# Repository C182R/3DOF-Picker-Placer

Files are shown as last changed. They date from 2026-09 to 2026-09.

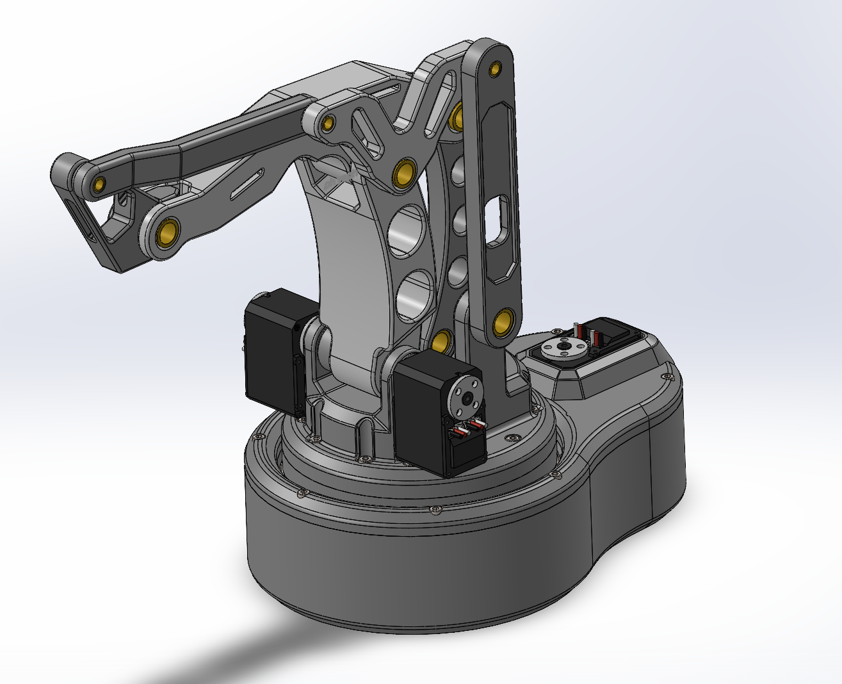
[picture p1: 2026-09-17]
docs/images/assembly with servos v3.png

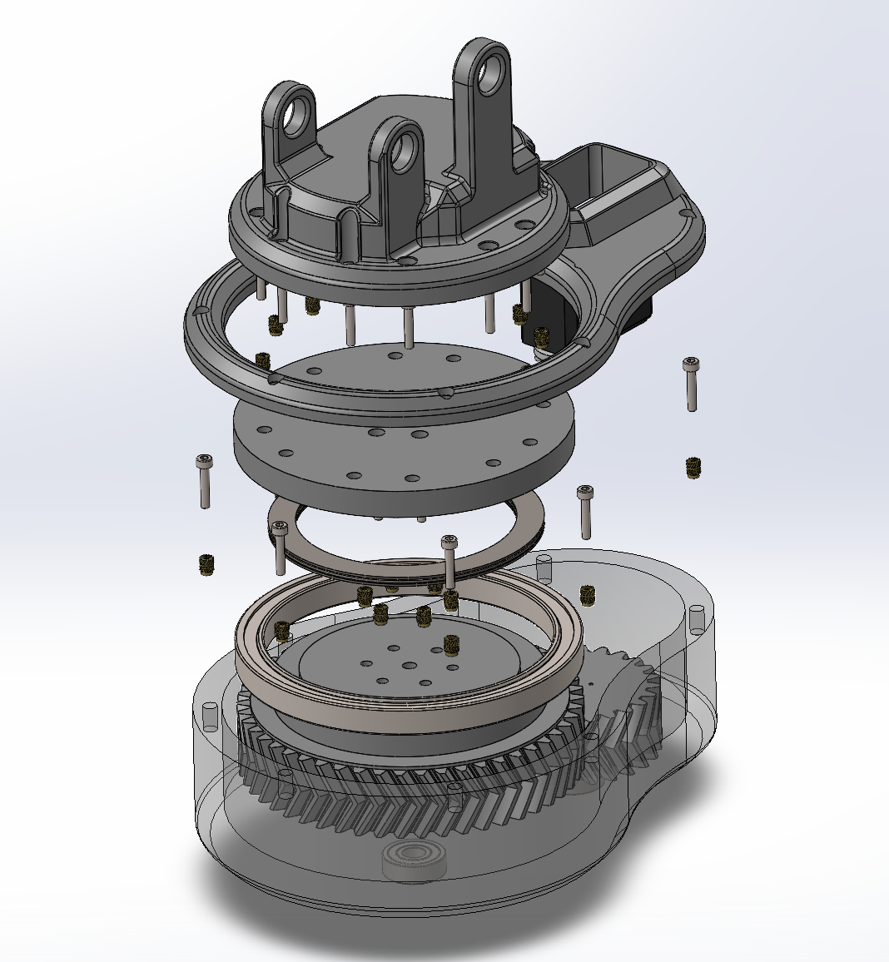
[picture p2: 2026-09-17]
docs/images/base assembly exploded view v3.png

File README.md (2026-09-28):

# 3DOF-Picker-Placer: Palletino

*Work-in-progress*



A cheap, easily-assembled, trainable 3-DOF robot arm, designed so anyone could build one from a parts list. Built around a parallelogram linkage topology referenced from Fanuc/KUKA/Panasonic palletizing robots, with topology-optimized structural links for FDM printing.

## Goals
- Cheap, off-the-shelf smart servos + printed structure, no exotic parts
- Easy to assemble: clear BOM, standard fasteners, no proprietary hardware
- Precise, not sprawling; deliberately 3 DOF (waist / shoulder / elbow) instead of chasing 6 DOF. The bet is that a tight, repeatable 3-DOF arm is more useful than a loose 6-DOF one, and it keeps cost and build complexity down
- Trainable — kinesthetic teach-and-repeat via torque-disabled smart servos, no separate programming step needed to record a motion (in progress)
- Modular at the tool end: swappable tool heads (dial gauge for precision validation, vacuum head for palletizing/pick-and-place, optional 4th-DOF wrist) instead of building capability into the arm itself

## Status
V2 base (waist joint, herringbone 2:1 reduction, swivel bearing) designed and being added to the repo. Firmware not yet started. See devlogs for the full history.

### Specs at a glance
	
- DOF 3 (waist, shoulder, elbow) + optional 4th-DOF tool head
- Actuators	3× Feetech STS3215 smart servo, daisy-chained
- Controller	ESP32 + Waveshare Bus Servo Adapter (UART)
- Power	USB-C PD (20V, primary) or XT60 bench/battery tap (alternate) → 12V servo bus / 5V logic
- Structure	FDM PETG (V1/V2), aluminum machining planned for later versions
- Base reduction	2:1 herringbone gear, waist joint

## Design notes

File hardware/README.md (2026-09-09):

# /hardware

SolidWorks source files and exports are here. The most up-to-date design files of the project

```
hardware/
├── solidworks/        # .SLDPRT, .SLDASM, .SLDDRW source files
├── step/               # .STEP exports — for anyone opening this in non-SolidWorks CAD, ready to slice
```

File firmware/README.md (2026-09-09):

# /firmware

ESP32 control code goes here once it exists. Planned scope:

- STS3215 bus servo driver over UART (via the Waveshare Bus Servo Adapter)
- Joint position read/write + torque-disable for kinesthetic teach mode
- Teach-and-repeat: record demonstrated motions, play them back
- Eventually: a tool-head interface layer so swapping tool heads (dial gauge, vacuum, 4th-DOF wrist) doesn't require rewriting the core motion code

Nothing's written yet.. this is a placeholder so the repo structure is ready when it is.

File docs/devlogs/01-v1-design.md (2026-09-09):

# Robot Arm Build — Devlog #1: V1 Design

**Date:** August 25, 2026

## Overview

This is v1 of the overall robot arm build, which is a 3 DOF antagonistic drive pick and placer, inspired by factory palletizing robots. The first physical version of a linkage-driven arm I've been working on in SolidWorks. I've already got a few issues with this version, just from looking at it on screen, but I'm going to 3D print it to see how it actually behaves in the real world before making changes.

## Design Approach
I used existing automation robot references for primitive geometry; I pulled references from Fanuc, KUKA, and Panasonic industrial/palletizing robots. These companies have decades of field-proven arm geometry behind them, so rather than guessing at joint offsets and link ratios from scratch, I used their designs as a sanity check for what actually works in practice. I'm already researching their electronic work using different control options like CANBUS and EtherCAT to implement (at least one version) into this robot.

**Topology optimization for the big structural pieces**
For the largest (by volume) components (anything with organic-looking cutouts or holes) I ran SolidWorks' topology optimization instead of hand-sketching lightening patterns. To make sure my studies were actually improving my design instead of making it worse, I cross referenced different parts across the industry (excavators, cranes, and other heavy equipment, since an excavator is what inspired me to create this robot) and used my knowledge in steel mechanics to see if a part would hold from a glance.

**Industrial robot references for the geometry**
For the practical link geometry and proportions, I pulled references from Fanuc, KUKA, and Panasonic industrial/palletizing robots. These companies have decades of field-proven arm geometry behind them, so rather than guessing at joint offsets and link ratios from scratch, I used their designs as a sanity check for what actually works in practice.

**DFM for FDM — with an eye toward aluminum later**
I designed with FDM 3D printing's strengths and weaknesses specifically in mind: layer orientation, load direction relative to layer lines, wall thickness, rather than just printing "machined part" geometry and hoping it holds up. At the same time, I kept track of which components are candidates to eventually remake in aluminum if the design is proven out, so the plastic-specific DFM choices don't paint me into a corner for a metal version down the line.

## What's Next
Print V1 and put it through real motion / hand-stress testing to confirm (or rule out) the issues I'm already suspecting. Then, I'll revise the design based on what breaks, binds, or flexes more than it should have. After, I'll start on the electronics side, although I'm going in with limited parts on hand, so that'll be its own challenge.

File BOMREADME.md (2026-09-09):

BOM.csv is for review.
BOM.md is the mockup as a basis for the main components needed.
In the future after accurate cost calculation, the price of assembling one robot with only the necessary components will be compiled into another document

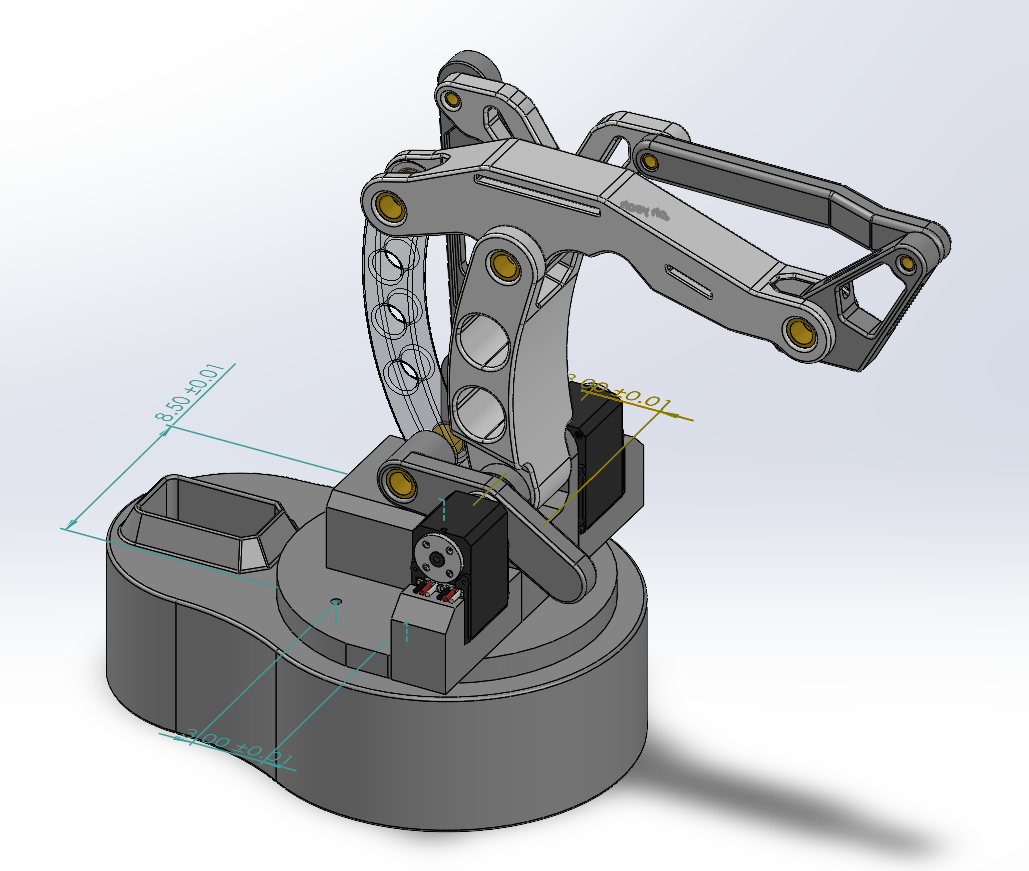
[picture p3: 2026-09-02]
docs/images/v2-base-overview.png

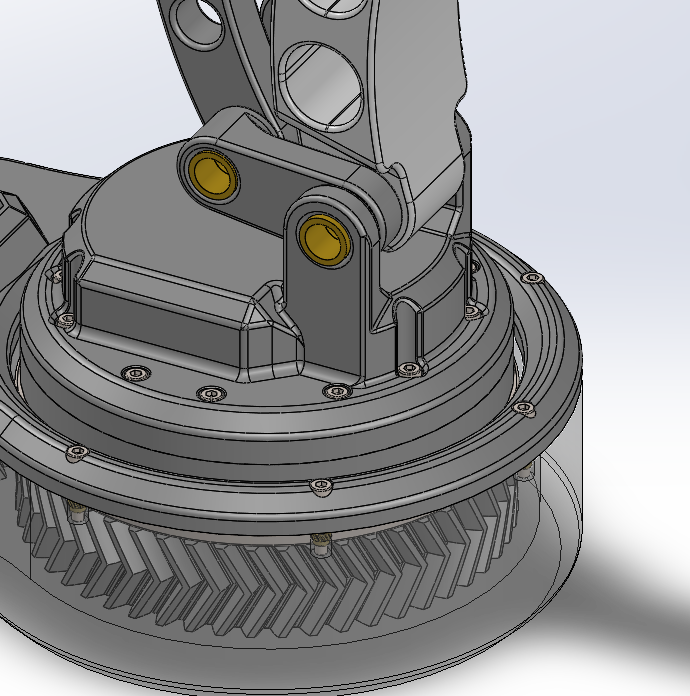
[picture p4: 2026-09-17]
docs/images/design change in v3.png

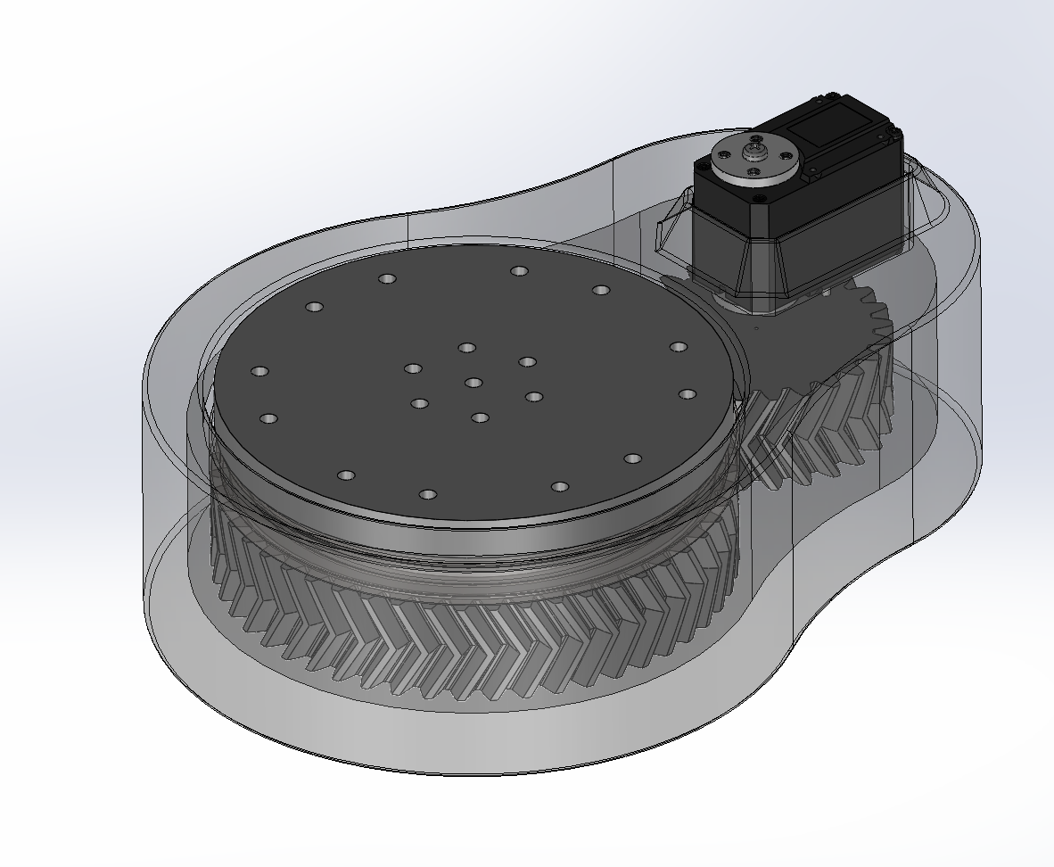
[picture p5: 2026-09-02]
docs/images/v2-base-cutaway.png

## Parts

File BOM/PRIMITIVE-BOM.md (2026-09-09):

# Bill of Materials (living doc)

Components finalized so far. Pricing/links intentionally left blank. 3D printed parts should have files included in /hardware

## Actuation
| Qty | Part | Notes |
|---|---|---|
| 3 | Feetech STS3215 smart servo (12V, 30 kg·cm, 1:345) | Waist, shoulder, elbow. Built-in 12-bit magnetic encoder + serial bus daisy-chain + torque-disable for kinesthetic teaching |

## Control
| Qty | Part | Notes |
|---|---|---|
| 1 | ESP32 dev board | Main controller |
| 1 | Waveshare Bus Servo Adapter (A) | Jumper set to UART mode; drives the STS3215 daisy chain |

## Power
| Qty | Part | Notes |
|---|---|---|
| 1 | CH224K USB-C PD trigger board | Set to 20V — mandatory PDO on 65W+ chargers |
| 1 | USB-C receptacle / breakout | Mount the CH224K's own USB-C connector directly at the panel edge rather than routing through a separate panel-mount breakout — many cheap breakouts drop the CC lines and silently kill PD negotiation |
| 1 | USB-C PD charger, 65W+ | USB-C laptop charger works fine, but should be separate from USB C data cable |
| 1 | XL4016 buck converter | Trimmed to 12V for servo bus |
| 1 | MP1584 mini buck converter | Set to 5V, feeds ESP32 VIN |
| 1 | 7.5A inline fuse | |
| 1 | SPST master switch | |
| 1 | 2200µF 25V low-ESR electrolytic cap | Across servo adapter power terminals |
| 1 | SMBJ14A TVS diode | Across servo adapter power terminals |
| 1 | XT60 connector | Tapped upstream of fuse, for bench supply |
| 1 | Mini voltmeter/ammeter module | Diagnostics |

## Structure
| Qty | Part | Notes |
|---|---|---|
| — | PETG filament | Primary structural material for FDM prints |
| — | M3 shoulder screws | Pivot pins — do not substitute printed pins |
| — | Herringbone ring gear + pinion (base) | 2:1 reduction, printed |
| — | Swivel bearing interface (base) | Simple flat swivel, not crossed-roller |
| 1 | Mini voltmeter/ammeter module | Diagnostics |

### Input Path B -- XT60 (bench supply, battery)
| Qty | Part | Notes |
|---|---|---|
| 1 | XT60 connector | Tapped upstream of fuse, for bench supply |
| - | External ~20V DC source | Bench supply, or a 5S LiPo + charger (~18.5–21V) if going battery-powered |

## Structure
| Qty | Part | Notes |
|---|---|---|
| — | PETG filament | Primary structural material for FDM prints. PLA will suffice for any low friction surface |
| — | M3 shoulder screws | (Ideally) Pivot pins. Substitute with PETG rods included in /hardware for primitive version |
| — | Herringbone ring gear + pinion (base) | 2:1 reduction, PETG printed |
| — | Swivel bearing interface (base) | Simple thrust roller bearing + roller/ ball bearing |

## Not yet finalized
- Vacuum pickup tool head (pump, nozzle, fittings)
- Dial gauge + mount
- Optional 4th-DOF wrist module

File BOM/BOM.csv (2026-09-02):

Category | Part Name | Spec / Size | Pack Qty | Cart Qty | Unit Price | Line Total | Notes | Link
Servos | FEETECH STS3215 30kg Smart Servo | 12V bus servo w/ magnetic encoder | 2 pcs/pack | 2 | $48.99 | $97.98 | 2x 2-packs = 4 servos total; 5% multi-buy discount noted in cart
Control | Waveshare Bus Servo Driver Board | Serial bus power + control circuit | 2 pcs/pack | 1 | $19.99 | $19.99 | ST/SC series bus servos. Jumper on position A for UART
Control | ELEGOO ESP-32 Dev Board | ESP-WROOM-32 USB-C WiFi/BT | 3 pcs/pack | 1 | $19.99 | $19.99 | Main controller board
Power | Seloky USB-C PD Trigger Board | PD/QC decoy, DIP-selectable 5-20V | 4 pcs/pack | 1 | $9.99 | $9.99 | CH224K-based. SET DIP TO 20V (not 12V). Mount at panel edge - use its own USB-C socket
Power | HiLetgo XL4016 Buck Converter | 4-40V to 1.25-36V 8A 200W | 2 pcs/pack | 1 | $10.99 | $10.99 | 20V->12V servo rail. Set output to 12.0V BEFORE connecting any load
Power | EBOOT MP1584EN Buck Converter | 24V to 12/9/5/3V adjustable | 6 pcs/pack | 1 | $12.55 | $12.55 | 12V->5V ESP32 rail. Taps rail UPSTREAM of E-stop so logic survives a stop
Power | Rubycon Electrolytic Capacitor | 2200uF 25V 12.5x25mm low-ESR | multi-pack | 1 | $6.99 | $6.99 | Across servo adapter power terminals. Stripe to ground
Protection | Chanzon SMBJ15A TVS Diodes | 600W 15V unidirectional | 50 pcs/pack | 1 | $5.99 | $5.99 | Across servo adapter power terminals. Banded end to +12V
Protection | Automotive Blade Fuse Assortment Kit | 5-30A ATC/ATO | 140 pcs/pack | 1 | $9.97 | $9.97 | Start with 7.5A, step to 10A only if nuisance blows
Protection | 10AWG Inline Fuse Holder | 40A ATC blade | 4 pcs/pack | 1 | $9.99 | $9.99 | 7.5A fuse on servo rail. Oversized for 16AWG - watch the crimp
Safety | TWTADE 22mm E-Stop Mushroom Button | 2NC 10A 600V | 1 pc | 1 | $14.99 | $14.99 | 1 contact breaks servo rail, 1 contact to ESP32 GPIO as sense
Switches | Nilight 90012E Rocker Toggle Switch | SPST 15A 250V / 20A 125V | 5 pcs/pack | 1 | $9.34 | $9.34 | Master power switch (storage/transport, not emergency)
Diagnostics | bayite DC Volt Meter | 0-30V 3-wire red LED | 5 pcs/pack | 1 | $9.99 | $9.99 | Consider swapping to a volt+amp combo module - current is the useful number
Cables | Cable Matters USB-C Gen2 Cable | 10Gbps 100W 3.3ft | 1 pc | 1 | $12.99 | $12.99 | Host data cable to servo adapter
Wiring | Haerkn 16AWG Silicone Wire | 2-core | 30ft spool | 1 | $17.88 | $17.88 | 12V rail wiring
Wiring | ELEGOO Dupont Wire Kit | 120pcs M-F / M-M / F-F, 8 inch | 120 pcs/pack | 1 | $6.98 | $6.98 | ADDED - ESP32 to servo adapter UART + 5V logic
Bearings | uxcell Flange Sleeve Bearings | 8mm Bore x 10mm OD x 12mm L, sintered bronze | 12 pcs/pack | 1 | $9.69 | $9.69 | ADDED - main pivots. Flange doubles as thrust washer between links
Bearings | uxcell Sleeve Bearings | 5mm Bore x 8mm OD x 10mm L, sintered bronze | 20 pcs/pack | 1 | $8.69 | $8.69 | ADDED - smaller wrist / bellcrank pivots
Bearings | SHKI 608-2RS Ball Bearings | 8x22x7mm, double rubber sealed | 20 pcs/pack | 1 | $6.99 | $6.99 | ADDED - gear shafts for 120mm herringbone + 60mm pinion (2:1)
Bearings | uxcell Deep Groove Ball Bearing 6816-2RS | 80x100x10mm | 1 pc | 1 | $13.89 | $13.89 | Rotating swivel base
Bearings | uxcell NTA4860 Thrust Needle Roller Bearings | ID 3" OD 3-3/4" x 1/8", w/4 washers | 2 sets/pack | 1 | $13.79 | $13.79 | Rotating swivel base - kept per your call
Fasteners | MECCANIXITY Shoulder Bolt | 8mm shoulder dia x 50mm, M6x1 thread, 304 SS | 4 pcs/pack | 1 | $9.39 | $9.39 | ADDED - long pivot pins, double shear through 8mm bushings
Fasteners | uxcell Shoulder Bolt | 8mm shoulder dia x 25mm, M6 thread, 304 SS | 5 pcs/pack | 1 | $9.99 | $9.99 | ADDED - short pivot pins, 8mm bushings
Fasteners | MECCANIXITY Shoulder Bolt | 5mm shoulder dia x 25mm, M4x0.7 thread, 304 SS | 16 pcs/pack | 1 | $8.90 | $8.90 | ADDED - pivot pins for 5mm bushings
Fasteners | Quacc M6 Nyloc Steel Nuts | M6, 304 SS nylon-insert | 20 pcs/pack | 1 | $3.69 | $3.69 | ADDED - retains M6 shoulder bolts, no M6 inserts needed
Fasteners | ruthex M4 Threaded Inserts (Brass Heat Set) | M4x8.1 | 50 pcs/pack | 1 | $9.99 | $9.99 | For 3D printed parts + M4 shoulder bolt threads
Fasteners | ruthex M3 Threaded Inserts (Brass Heat Set) | M3x5.7 | 100 pcs/pack | 1 | $9.99 | $9.99 | For 3D printed parts
Fasteners | Wensilon M3 Nylon-Insert Lock Nuts | M3 SS | 100 pcs/pack | 1 | $6.99 | $6.99 | Long screws requiring clamping force
Fasteners | BinifiMux M4 Self-Lock Nylon Nuts | M4 x 0.7mm | 40 pcs/pack | 1 | $4.99 | $4.99 | Long screws requiring clamping force
Fasteners | Fgruh M4 Socket Screw Assortment Kit | M4x6-30mm w/ nuts & washers | 490 pcs/pack | 1 | $9.99 | $9.99 | Will change in further designs
Fasteners | Fgruh M3 Hex Socket Screw Assortment Kit | M3x6-30mm w/ nuts & washers | 720 pcs/pack | 1 | $9.99 | $9.99 | Will change in further designs
Tools | FFVRVSS Heat Set Insert Tool | 7x soldering tips M2-M8, T18 adapter | 1 kit | 1 | $5.99 | $5.99 | ADDED - required to install the ruthex inserts
Filament | Polymaker PETG Filament | 1.75mm 1KG Galaxy Black | 1 kg | 1 | $21.99 | $21.99 | Structural links. See note on PLA creep
Filament | Polymaker PLA Pro Filament | 1.75mm 1KG Black | 1 kg | 1 | $19.79 | $19.79 | Enclosure / non-load-bearing. Limited-time -10% deal applied
 |  |  |  |  | TOTAL | $461.33 | without tax + shipping
REMOVED FROM v1
Connectors | Type-C Female Chassis Panel Jack | 2-pin 22AWG waterproof |  |  | $10.90 |  | 2-pin = no CC lines = PD never negotiates. Trigger board mounts at panel instead
Bearings | uxcell Sleeve Bearings | 3/8" Bore x 1/2" OD x 3/4" L, Brass |  |  | $13.29 |  | Imperial bore, no metric pin fits - 1.5mm slop with M8
Bearings | HiPicco Sleeve Bearing | 1/2" Bore x 5/8" OD x 5/8" L, Brass |  |  | $13.99 |  | Imperial bore + heavily oversized for the loads
 |  |  |  |  | REMOVED TOTAL | -$38.18

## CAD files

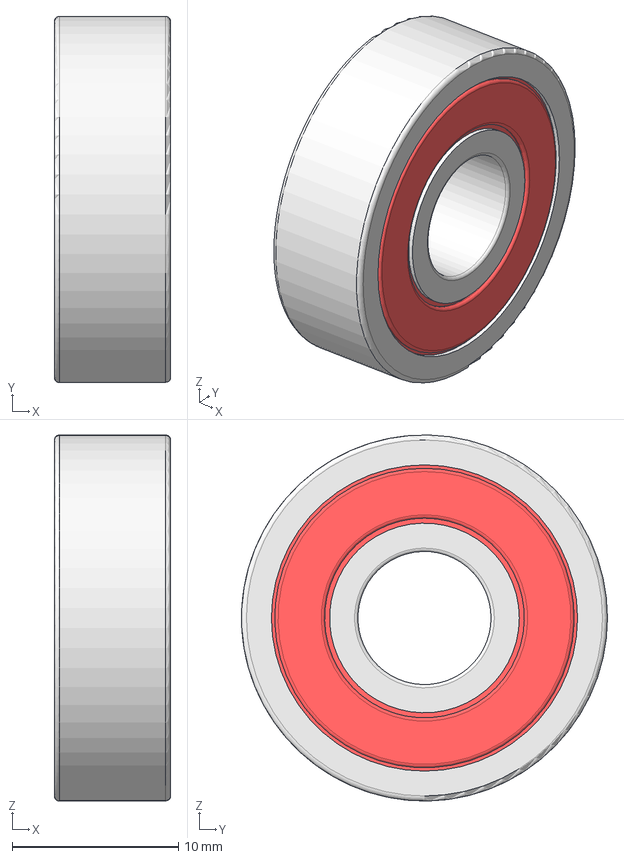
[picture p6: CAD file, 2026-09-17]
hardware/608-2RS Ball Bearing/608-2RS Skate Board Ball Bearing.step
7.00 x 22.0 x 22.0 mm
Ball 001
Ball 002
Ball 003
Ball 004
Ball 005
Ball 006
Ball 007
Outer Ring001
Inner Ring001
Seal 001
Seal 002
Cage 001
Cage clone 002
Rivet 002
Rivet 001
Rivet 007
Rivet 006
Rivet 005
Rivet 004
Rivet 003

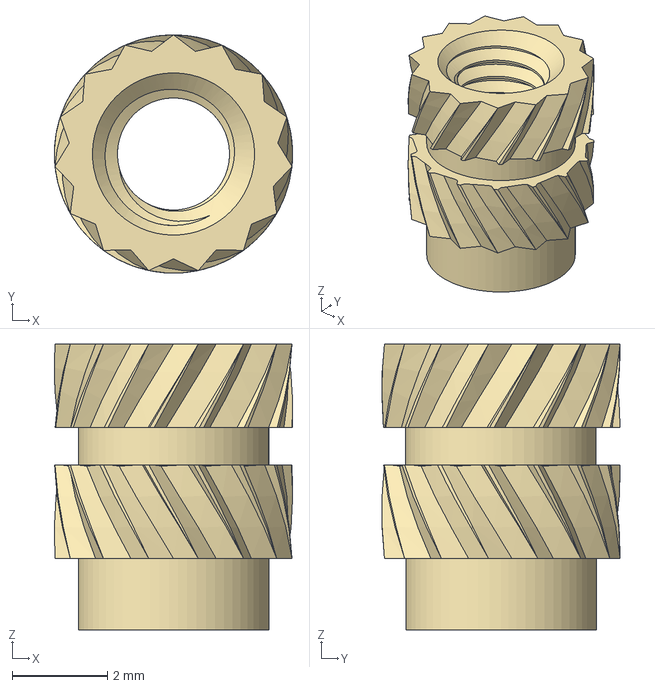
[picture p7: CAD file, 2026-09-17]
hardware/Insert M3 D5 L5mm/Insert M3 D5 L5mm.stp
5.00 x 5.00 x 6.00 mm

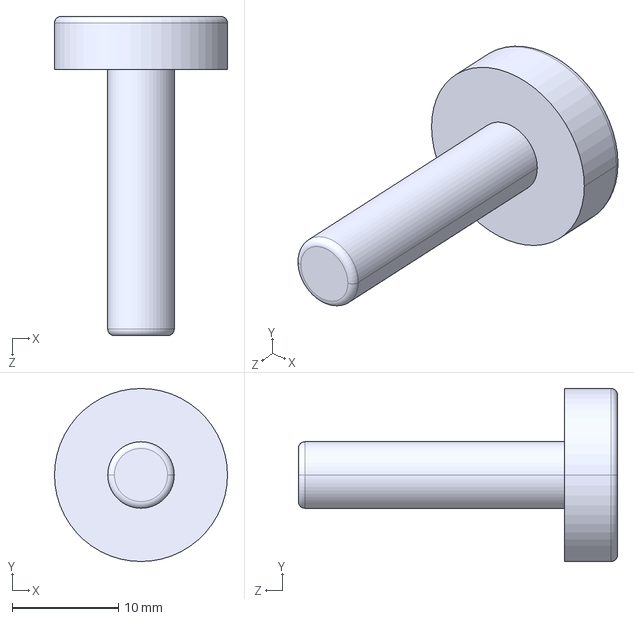
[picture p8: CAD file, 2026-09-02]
hardware/step AP214/v1 (primitive, no electronics)/.25in 2.25cm x 1.STEP
16.2 x 16.2 x 30.0 mm

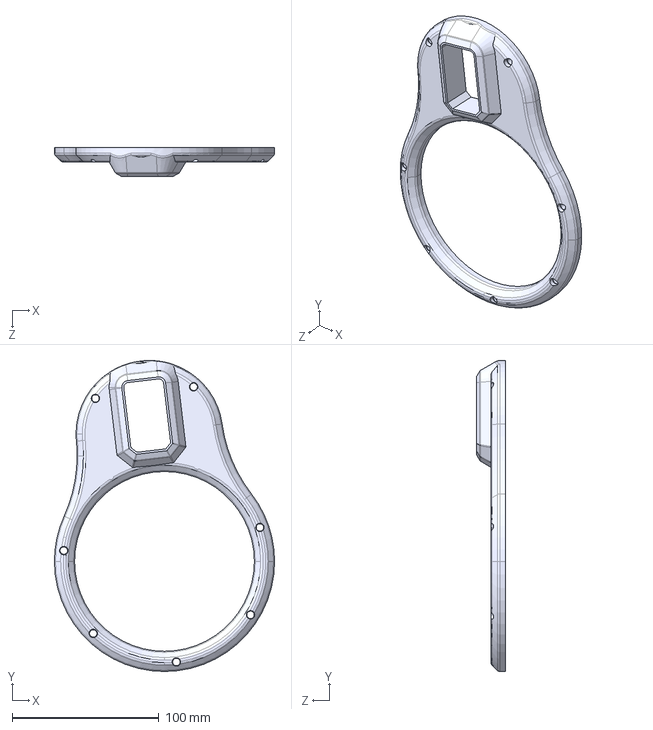
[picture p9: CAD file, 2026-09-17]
hardware/step AP214/v3/top housing.STEP
150.0 x 211.9 x 20.0 mm

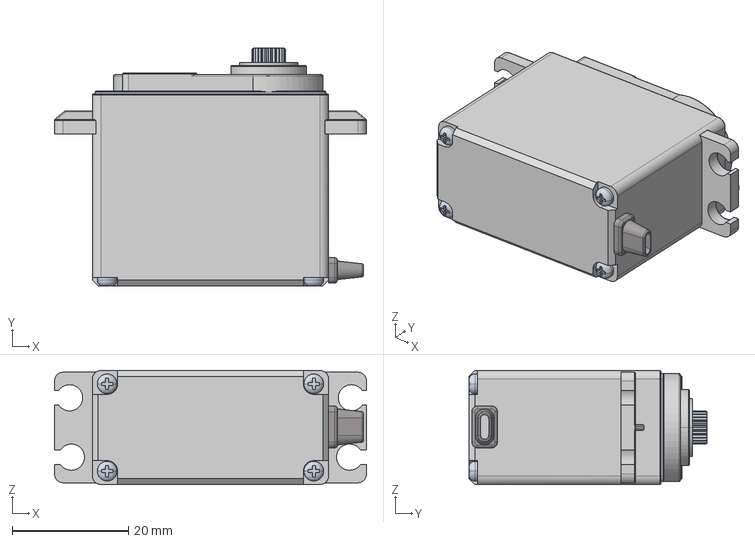
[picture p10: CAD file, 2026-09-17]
hardware/hitec hs-425bb servo/HS-425BB-1642818544.stp
53.6 x 40.9 x 19.6 mm

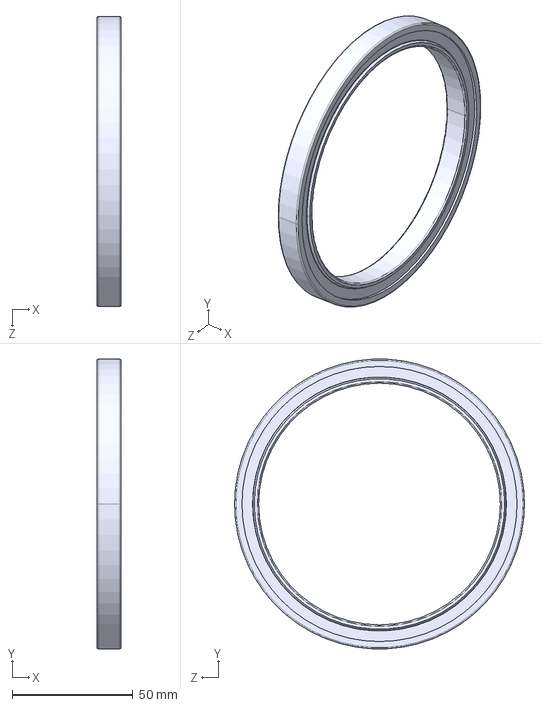
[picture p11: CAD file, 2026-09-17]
hardware/step AP214/v3/radial cylindrical roller bearing_am_AFBMA 20.1 - 17-100 - 54,SI,NC,54.STEP
10.0 x 119.8 x 120.0 mm

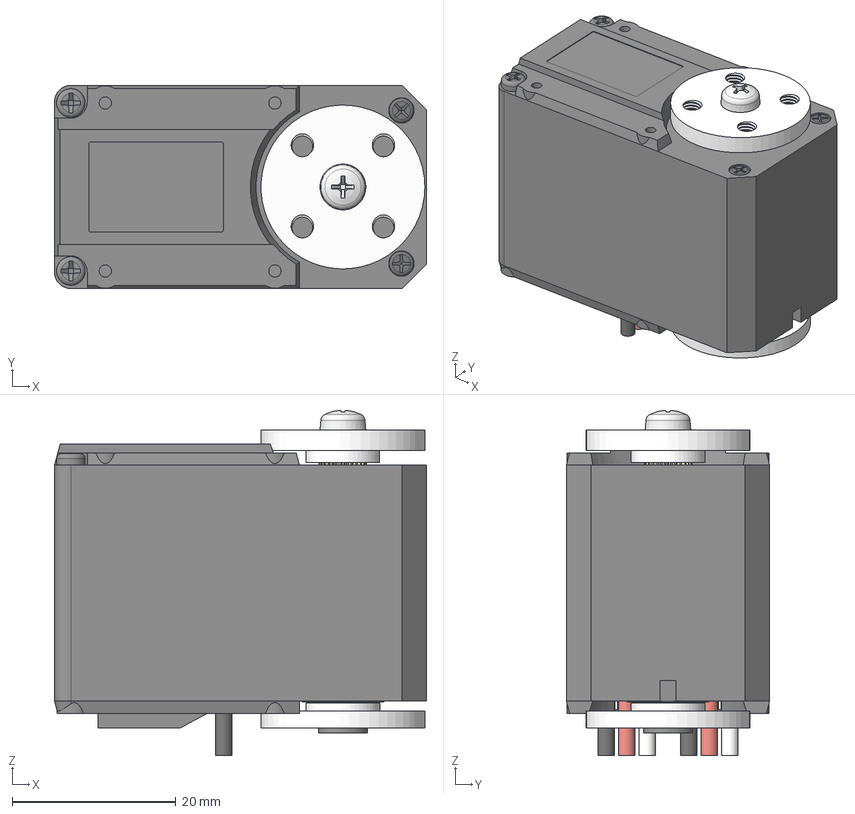
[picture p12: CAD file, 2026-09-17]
hardware/sts3215-v10 servo/servo-motor_sts3215-v10.step
45.4 x 24.8 x 42.1 mm
Composant2
Composant3
Composant4
vis x 2
connector F x 2
PHS JIS B 1111 - M3 x 4 - H Acier inoxydable A2 Standard

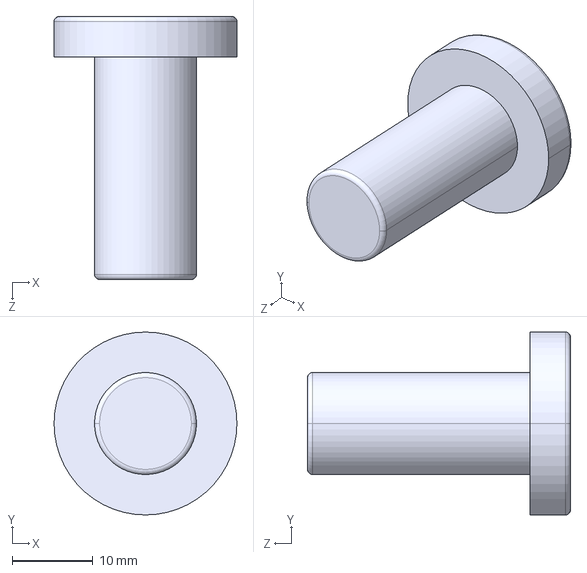
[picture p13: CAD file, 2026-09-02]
hardware/step AP214/v1 (primitive, no electronics)/.5in 2.5cm x 2.STEP
22.6 x 22.6 x 32.5 mm

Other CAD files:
hardware/solidworks/v3.1/base bearing assembly.SLDASM
hardware/solidworks/v3.1/the john v2.SLDASM
hardware/step AP214/v3/base bearing assembly.STEP
hardware/solidworks/v3.1/3in thrust bearing.SLDASM
hardware/.3mf/linkages.gcode.3mf
hardware/hitec hs-425bb servo/HS-425BB-PART.SLDPRT
hardware/solidworks/v1 (primitive, no electronics)/.25in 2.0cm x 2.SLDPRT
hardware/sts3215-v10 servo/servo-motor_sts3215-v10-PART.SLDPRT
hardware/.3mf/rods, clips, and spacers.gcode.3mf
hardware/step AP214/v3/servo-motor_sts3215-v10-PART.STEP
hardware/608-2RS Ball Bearing/608-2RS Skate Board Ball Bearing.SLDPRT
hardware/Insert M3 D5 L5mm/Insert M3 D5 L5mm.SLDPRT
hardware/hitec hs-425bb servo/HS-425BB-1642818544.SLDASM
hardware/solidworks/v1 (primitive, no electronics)/.25in 2.25cm x 1.SLDPRT
hardware/solidworks/v1 (primitive, no electronics)/.5in .125cm spacer.SLDPRT
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

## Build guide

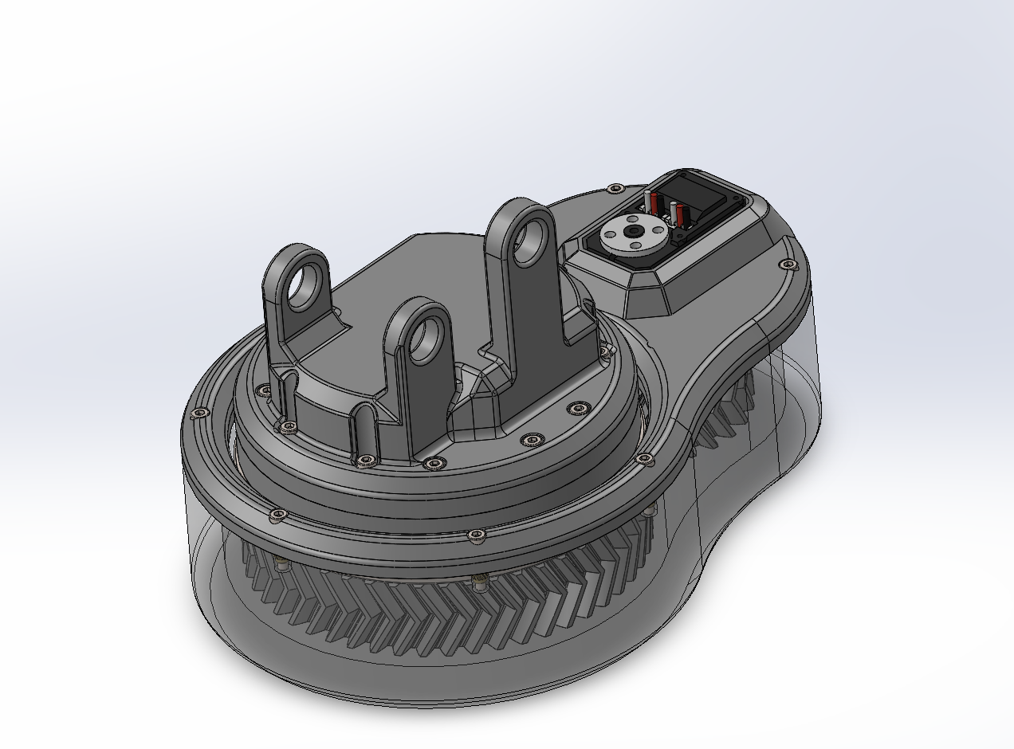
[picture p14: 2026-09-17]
docs/images/base assembly v3.png

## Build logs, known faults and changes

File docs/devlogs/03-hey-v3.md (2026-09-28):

# Devlog #3 — Hey v3

**Date:** September 17, 2026

This round was all about getting the design closer to the final product, mainly the robot base and the swivel base assembly. A lot more is actually in the CAD now: screws, heat-set inserts, bushings, bearings, and servos. I also designed the parts that mount the main arm assembly to the swivel deck, and fixed a handful of my own design setbacks and assembly issues that only showed up once real hardware was in the model.

## The base, fully detailed

From top to bottom, the stack is:

- the rotating deck with the mounts for the arm
- the top cover with the pocket for the J1 servo
- a hub plate
- the thrust roller bearing
- the deep groove ball bearing
- the 2:1 herringbone gear
- the housing, with a 608 bearing at the bottom for the gear shaft

Every screw that goes into plastic lands in a brass heat-set insert instead of printed threads. PETG threads strip after a few cycles, and this guy will probably get taken apart a lot during build prototyping. Modeling the actual screws also forced me to check head clearance, screw lengths, and whether an allen key or t-handle can even reach them once everything's stacked. It was boring but worth it.

The swivel deck is now the real interface between the base and the arm. The two J2 servos will sit on either side of the deck, and every arm pivot gets a bronze bushing as a cheap, replaceable wear surface. The pins and bushings carry the linkage loads, so the servos only have to supply torque instead of holding the arm up by their splines. I thought of direct driving just now, but it's currently just a thought.

## Some setbacks

- **The coupling with the curved support linkage.** After realizing some ROM by messing around a lot with the assembly, realized the front counterweight option I planned for had to go. To add, I moved the mounting towards the inside of the base instead of on the outside, which should give me some more movement liberty in the long term.
- **The actual shape of the robot base.** I rounded it out and focused on symmetry so I would have an easier time assembling. Converting to a circular shape and not just the simplest form also opened the gate for more equalized load bearing.

## Reality check !!

I don't have any of the hardware yet, so everything is designed off online CAD models. From experience, that'll set me back once the real parts show up.. nothing is ever perfect without real references.

- Downloaded models are usually nominal or simplified.
- Heat-set insert hole sizes change by brand.
- Bearing fits depend on the printer.
- Some more boring stuff that don't match up irl

So I'm trying to keep the critical interfaces easy to tweak, and once everything arrives I'll print small fit tests before committing to full parts.

## Next up I'm planning to..

- Give the arms the same treatment: pins, bushings, spacers, fasteners, the works.. and making it look super wicked. Still, functionality first.
- Double-check shoulder screw lengths against the bushing stacks.
- Update the BOM with the real fastener and insert counts.

The tool-head standard and the 1:1/direct drive question are still on the list too, but those have to wait for hardware.. gabagoo.

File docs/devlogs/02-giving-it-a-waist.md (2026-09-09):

# Devlog #2 — Giving the Arm a Waist

This is v2.

## What's new

I designed the full base assembly: outer shell, swivel bearing interface, and rotating deck. The waist joint (J1) driven by a 2:1 herringbone gear reduction off a STS3215. After research, I chose to use these motors with a 345:1 @12V on each, up to four motors total: one for the yaw, 2 powering the shoulder linkage (J2), and another for an eventual 4th DOF (J4) on the toolhead. This tiny motor already has a built in 12-bit encoder, which eliminates the need for an additional electronic part, aka additional point of failure.

Nailed down the project's actual design goal (see below — this matters more than it sounds)
Started thinking seriously about tool-head modularity for the business end of the arm.

## The base / waist joint

**Mechanism:** Servo-driven pinion → herringbone ring gear on the rotating deck, 2:1 reduction.

I decided on herringbone gears since they self-cancels axial thrust; a straight spur or single-helical gear at this scale wants to walk sideways under load, herringbone doesn't (that much). Plus, I'm 3D printing it, so machining manufacturing isn't a concern (yet). I also use a deep groove ball bearing on the outside for smooth rotation and a thrust roller bearing on top to reduce my axial loads. Initially, I was planning to use opposing tapered roller bearing, but this approach is cheaper (and lighter..).

For the 2:1 ratio, my main motivator was to get the least strain (and heat) on the only tiny motor carrying the weight of the entire robot (excluding payload). Using torque calculations, I realized that the 2:1 might be unnecessary and slow, so I already envision converting to a 1:1 or direct drive mechanism after seeing the arm in action. In the next iteration, I'll tackle the modularity of the bearing base to be able to use an assortment of different sized bearings and sprockets, making it easier for anybody wanting to give the build a shot. My only concern is that this joint could be a silent generator of slop, which can hopefully be mitigated by the servo encoder.

**Electronics:** Base servo joins the same daisy-chained bus as the shoulder and elbow servos through the Waveshare adapter. Still 3 wires, still one UART line. Diving more into this later on.

## The goal

While most hobby arm projects chase 6 DOF because that's what "real" robots have, I'm deliberately not doing that. It's kind of overdone/ overrated, but it still amazingly effective. This robot has a different purpose.

**The actual goal:** A cheap, consistently precise 3-DOF arm waist, shoulder, elbow, amazing to use by itself but increasingly more capable with added attachments/ accessories.. a bit like an Ender 3..lol. That's the basis of the palletizing topology this guy was inspired by in the first place; those robots don't need a wrist full of DOF to do useful, precise, and repeatable work, and one robot can be adjusted/ modified to perform a plethora of tasks. Precision, repeatability, and real world practicality is the actual metric I'm chasing, not DOF count. In my eyes, I don't want to build this guy and be done with him, I want to get and learn the most of the robot, especially since he'll be mostly plastic.

## Modularity: the tool end is the extensibility point

Instead of building DOF into the arm, the plan is to build capability into swappable tool heads at the end effector. Same 3-DOF base arm, different job depending on what's connected on, for instance:

- **Dial gauge mount** — turns the arm into its own precision-measurement rig. Point it at a fixed reference, cycle the joints, read the repeatability directly off the gauge. Built-in self-validation for the "consistently precise" claim. (idea!). Even if it not an actual dial gauge (since those things are serious measuring apparatus), something similar than can display the precise repeatability. 
- **Vacuum pickup head** —  palletizing demo, the original inspiration for the geometry. Palletizing is actually a main driver on why the linkages are designed like they are. They're designed to hold REAL weight, with some FANUC and KUKA robots with similar linkages designed to precisely pick and place 700kg payloads.
- **4th DOF module** — an optional wrist rotation attachment for tasks that actually need it, without making it a tax on every build.

The design constraint going forward: every tool head shares a common mounting interface, so swapping between them is a bolt pattern away, not a redesign. That interface is the next thing I need to nail down before I start modeling individual tool heads.

## Next up I'm planning to..

- Finalize the tool-head mounting standard (connection pattern + electrical/pneumatic passthrough if needed for the vacuum head, but pneumatics should not be treated lightly, so I think this would be a final design).
- Print the base and validate the herringbone mesh + swivel fit in (preferably in) PETG
- Get all 3 servos on the bus talking together and do a first coordinated move

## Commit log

2026-09-02 Clarify 3D printed parts and hardware file locations
    Updated BOM.md to clarify file locations for 3D printed parts and hardware.
2026-09-02 Refine design documentation for robot arm v1
    Revised the overview and design approach sections for clarity and detail. Enhanced descriptions of topology optimization and industrial robot references.
2026-09-02 Fix merge conflicts and clean up BOM.md
    Removed duplicate entries and resolved merge conflicts in BOM.md.
2026-09-02 added dha bom.csv
    [bom_v2.csv]
2026-09-02 Add initial BOM documentation files
2026-09-09 added v2 files
    [.25in 2.0cm x 2.SLDPRT, .25in 2.25cm x 1.SLDPRT, .5in .125cm spacer.SLDPRT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]
2026-09-17 v3. changes, pics, cad
    [3in thrust bearing.SLDASM, 3in thrust bearing.STEP, 5909K281_0.032 Thick Washer for 3 Shaft Diameter Needle-Roller Thrust Bearing.SLDPRT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]
2026-09-26 v2 BOM
    [BOM.csv]
2026-09-26 added BOM.csv to BOM folder
    [BOM.csv]
2026-09-26 added BOMREADME.md to BOM folder
2026-09-26 added PRIMITIVE-BOM.md to BOM folder
2026-09-28 Added necessary pin connections
    [.25in 2.0cm x 2.SLDPRT, .25in 2.25cm x 1.SLDPRT, .5in .125cm spacer.SLDPRT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]
2026-10-22 added version 3.2v, with all electronics included in BOM, although it is not a final design. Updated a small item in the BOM.
2026-10-22 Add wiring section and diagram to README
    Added wiring section with diagram to README.
2026-10-22 Update wiring diagram formats in README
2026-10-22 Enhance wiring diagram with responsive images
    Updated wiring diagram to use responsive images for dark and light modes.
2026-10-22 Rename hero opposite assembly with servos & electronics v3.2.png to hero-v3.2
